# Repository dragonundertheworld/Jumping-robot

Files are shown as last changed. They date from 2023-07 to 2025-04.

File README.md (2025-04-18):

# Micro Small Intelligent Jumping Robot

Project details can be found in [notion link](https://cherry-room-163.notion.site/?pvs=4)

## Project Overview

This project, developed at the University of Electronic Science and Technology of China (UESTC), focuses on creating a micro-sized intelligent jumping robot. Unlike many biomimetic designs, this robot utilizes engineering principles and a carbon fiber structure to achieve significantly higher jump heights, potentially exceeding 5 meters. The goal is to develop a robot capable of navigating complex terrains with potential applications in reconnaissance and defense.

## Key Features & Components

*   **High-Performance Jumping:** Employs carbon fiber legs for efficient energy storage and release, enabling high jumps.
*   **Engineering-Based Design:** Focuses on mechanical principles rather than direct biological imitation for maximizing jump height.
*   **Motor-Driven Actuation:** Uses a [`GA12-N20`](assets/GA12-N20.SLDPRT) DC geared motor (6V, 50r/min, 298:1 ratio) to wind a rope, compressing the carbon fiber legs for energy storage.
*   **Mechanical Latch Release:** A custom [`latch`](assets/latch.SLDPRT) and release arm system ([`releasing arm2.SLDPRT`](assets/releasing arm2.SLDPRT), [`releasing arm3.SLDPRT`](assets/releasing arm3.SLDPRT)) triggered by a [`楔形.SLDPRT`](assets/楔形.SLDPRT) (wedge) on the rope provides a rapid release mechanism.
*   **Power Source:** Utilizes a compact 7.4V, 180mAh LiPo [`电池.SLDPRT`](assets/电池.SLDPRT) (battery).
*   **Lightweight Construction:** Incorporates carbon fiber and other lightweight materials. CAD models for components are available in the [`assets/`](assets/) directory, including the main [`组装体.SLDASM`](assets/组装体.SLDASM) (assembly).

## Jumping Mechanism

1.  The motor rotates, winding a rope attached to the carbon fiber legs via a [`拉绳板.SLDPRT`](assets/拉绳板.SLDPRT) (rope plate).
2.  The legs bend, storing elastic potential energy.
3.  A wedge fixed to the rope moves upwards as it's wound.
4.  The wedge contacts and pushes open the latch mechanism.
5.  The release arm, no longer supported by the latch, swings down due to rope tension.
6.  The rope rapidly unwinds from the motor shaft, releasing the tension on the legs.
7.  The carbon fiber legs snap back to their original shape, converting stored potential energy into kinetic energy, launching the robot upwards.
8.  Elastic bands reset the release arm for the next jump cycle.

## Current Status

*   A physical prototype has been constructed and tested.
*   Achieved an estimated jump height of approximately 5 meters.
*   The time interval between jumps is around 10 seconds.
*   Demonstrated partial capability for repetitive jumping.

## Future Work & Planned Improvements

*   Develop and implement control systems for jump direction and aerial attitude stabilization (potentially using IMU, GPS).
*   Enhance the reliability and reduce potential jamming of the release mechanism.
*   Address potential delamination issues with the carbon fiber legs after repeated stress cycles.
*   Integrate control components (microcontroller, sensors, wireless communication like Bluetooth).
*   Implement obstacle avoidance capabilities.
*   Refine the overall mechanical structure and component interactions.

## Team & Advisor

*   **Team Members:** Gou Xuning, Cao Zhihan, Cui Chenguang, Tan Peijie
*   **Advisor:** Wei Dunwen
*   **Institution:** University of Electronic Science and Technology of China (UESTC)

## Assets

The [`assets/`](assets/) directory contains SolidWorks CAD files (`.SLDPRT` for parts, `.SLDASM` for assembly) detailing the robot's mechanical design.

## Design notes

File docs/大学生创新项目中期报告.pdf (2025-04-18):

# 电子科技大学创新创业项目

# 中期报告

## 项目名称： 微小型智能跳跃机器人

## 组内成员：苟栩宁、曹知寒、崔晨光、谈培杰

指导教师： | 魏敦文

## 2023 年 4 月 23 日

I

摘要

本文主要研究一种基于工程原理的微小型智能跳跃机器人，其可在复杂环

境中实现跳跃，跳跃高度远超以往的仿生机器人，在国防军事领域存在极高的

应用前景。目前研究内容主要包括：设计了机器人基于碳纤维的跳跃组件，包

括碳纤维足、电机、锁存器、吊臂 、释放臂等部件，能够通过电机的旋转带动

实现机器人的准备及跳跃。同时初步探讨设计了机器人实现重复跳跃的组件，

为跳跃机器人的可持续性运行奠定了基础。

关键词：碳纤维足；跳跃机器人；重复跳跃

I

目录

摘要 | I

1.绪论

## 1.1 课题研究背景及意义

伴随着无人系统技术的发展，微小型仿生跳跃机器人通过模拟动物如蚂蚱

袋鼠关节运动机理实现高性能高能效的跳跃运动，跳跃运动借助关节高爆发

力，实现高速的离散运动步态，具有很好的越障性能，同时具有体积小、隐蔽

性好、重量轻、成本低等特点，非常适用于非结构环境下探测和侦察任务，在

国防领域和民用方面都有着广泛的应用前景。

随着研究的深入，发现制约其发展的最大因素就是跳跃机理不够清晰以及

设计什么样的储能爆发结构到仿生跳跃的效果还不明朗。所以项目的研究重点

在于仿蝗虫腿部结构、腿部柔性关节与超弹性的耦合以及控制等方面，从而提

升跳跃机器人的跳跃性能。在军事国防和民用方面都有着十分广阔的应用前

景。

## 1.2 研究现状

几个世纪以来，科学家们探索了生物跳跃高度的极限，几十年来，工程师

们设计的跳跃机器人经常模仿或从生物跳跃者中汲取灵感。国外机器人已有不

少成品，如月球弹簧高跷是模拟蚂蚱的弹跳；气动双足机器人模拟人类的跳

跃；四足机器人仿照青蛙的跳跃模式；为穿越崎岖路段分别结合了滚动和滑行

运动技术的机器人；水上跳跃机器人模拟水黾的动作等等。国内目前也有仿

猫、仿蚂蚱、仿水黾的跳跃机器人以及电磁驱动的小型跳跃机器人。

其中仿蝗虫机器人基于扭簧的弹性变形激励，采用微型马达对其先蓄能后

释放的方式完成跳跃运动。在转向问题上同样采用了支撑腿设计，该团队在该

机器人上的创新在于着重研究群机器人的路径规划问题，并考虑结合组网技术

将其应用在远程家庭环境监控领域。最新的小型跳跃机器人的设计重点在于分

析蝗虫的运动模式，实现了爬行和跳跃两类运动。

2016 年，李涛等人从微观上分析超疏水性材料的疏水作用机理，在此材料

研究基础上，结合水黾的生物特征和运动机理，将该材料作为机器人的足端设

计了一种仿生水黾机器人，并据此分析了仿生水黾机器人的运动特性，为该团

队后续对仿生水黾机器人的动力学研究打下了基础。在李涛等人的研究基础

上，该团队成员通过实验和仿真研究了所使用的弹簧刚度、起跳角度和脚掌面

积对于机器人起跳性能的影响。

但是相比之下，基于工程原理的机器人的跳跃高度可能要高得多，因为它

的棘轮或旋转电机可以在重复行程或旋转过程中使得做功倍增。由于能量产生

的差异，仿生跳跃机器人和工程跳跃机器人最大化跳跃高度的设计并不相同。

因此，我们计划创造一种可以跳跃更高的设备。据计算，这将远远高于以前的

仿生跳跃机器人，比最好的生物跳跃机器人高出一个数量级，而更高的跳跃高

度意味着能适应更复杂的地形并拥有更广泛的应用，因此无论是在军事上还是

工程上，这样的机器人都有极好的应用前景。

## 1.3 研究内容及文章结构安排

### 1.3.1 研究内容

本项目研究一种可以远程操控的小型智能跳跃机器人，具备实时图像传

输，记录并发送自己的当前位置、通过无线蓝牙模块与智能手机等通讯设备进

行通信、远程调整跳跃方向及高度以进行复杂地形空中侦察等功能。

本跳跃机器人由直流减速马达驱动机构、碳纤维弹片及橡皮筋储能机构、

自动释放装置、弹簧复位结构和智能控制系统组成。考虑机器人在空中的运动

特征，利用 IMU 传感器实时监测机器人的运动状态，根据传感器的数据通过运

动规划和闭环反馈控制调整机器人的跳跃方向，借助 GPS 实现定位。控制马达

不同的旋转时间改变弹簧蓄力，以控制不同的跳跃高度。机器人的自动释放装

置和弹簧复位结构由 solidworks 设计，然后由高精度 3D 打印机打印。跳跃机

器人系统由接收器和发射机实现远程控制，它向机器人体内的微型 arduino 计算

机发送信号以控制跳跃的方向和高度。为了让机器人能够执行侦查任务，我们

优化了机器人的结构，使它能够跳跃到足够的高度。并改进蓄能装置，使机器

人跳跃时间间隔大大缩短，以实现连续的工作。

为了实现上述功能，我们的设计方案主要如下：

该跳跃机器人包括轻型碳纤维跳跃结构、流线型破风机构、重心调整换向

结构、避障机构、支撑组件以及控制装置。

碳纤维跳跃结构包括: 跳跃用碳纤维片、十字形橡胶固定布、电机、弹簧

复位臂、闭锁以及多个钢质连接件。使用四个碳纤维作为跳跃主弓四个碳纤维

片在两端分别通过两个十字形橡胶固定布进行固定，下端与地面接触，上端通

过连接件与弹簧复位臂进行连接，弹簧复位臂上有一阻隔滑块，阻隔块连接在

绳上，绳随电机做往复运动，当阻隔滑块运动到与闭锁相接触时，滑块将闭锁

挤开，给予跳跃主弓巨大的瞬时力。从而通过电机的快速运动，实现跳跃主弓

的弯曲和复原，完成跳跃并落地，实现往复的运动过程。

流水线破风机构部分需要完成破风，使得跳跃式阻力更小，提高跳跃高

度。经过思考和实验，我们根据伯努利原理，设计了轻型材料制成的破风尖头

帽，该破风帽为流水线构型，能充分减少运动时的阻力。

重心调整换向机构包括舵机和质量块，控制元件接收到 app 传来的方向信

息或避障机构传来障碍物信息后，使舵机旋转一定的角度，从而使得质量块的

质量方向性发生改变，从而改变整体机构的重心，使机构的运动向目标方向转

换。

避障机构主要有使用深度相机和红外的双模控制，当相机和红外感受到前

方有障碍物时，会向控制芯片发送障碍物的位置信息，基于相机和红外的双模

工作，确保对障碍规避的稳定性。

控制装置具体包括：九轴传感器、电机通信模块、无线蓝牙通信模块、控

制芯片。以上传感器均安装在控制电路板上；控制电路板通过螺栓安装在与跳

跃机构的电机盒部分进行连接。值得注意的是，由于跳跃任务对轻型化的要

求，本次设计所使用的元器件均为低功率微型元件。

手机端 app，预期可以通过手机端向机构发送跳跃的方向、高度信息以及

实现跳跃机构的平稳停止，完成对机构的全方位控制。

### 1.3.2 文章结构安排

全文的章节安排如下：

第一章：首先简单介绍了微小型智能跳跃机器人课题的研究背景及意义；

然后介绍了目前相关仿生跳跃机器人的研究现状；最后描述了论文的研究内容

以及整体架构。

第二章：微小型智能跳跃机器人。介绍了目前本机器人的主要组成零件，

并对各零件的功能及参数进行了简要的介绍，也对跳跃机器人实现跳跃的整体

流程与原理进行了介绍。

第三章：项目研究结果。本项目建模并实现了一种微小型智能跳跃机器

人，基于碳纤维板的特性，突破了仿生机器人的生理极限，具有可观的跳跃高

度。同时指出了项目的部分创新点与后续的改进优化方向。

## 2.微小型智能跳跃机器人

在该项目中，机械部分的设计主要参考相关研究自主建模设计，采用质量

小、韧性强的碳纤维作为跳跃实现的主要部件，通过对电机的控制进而实现对

跳跃的控制，结构巧妙且具有极高的效率。

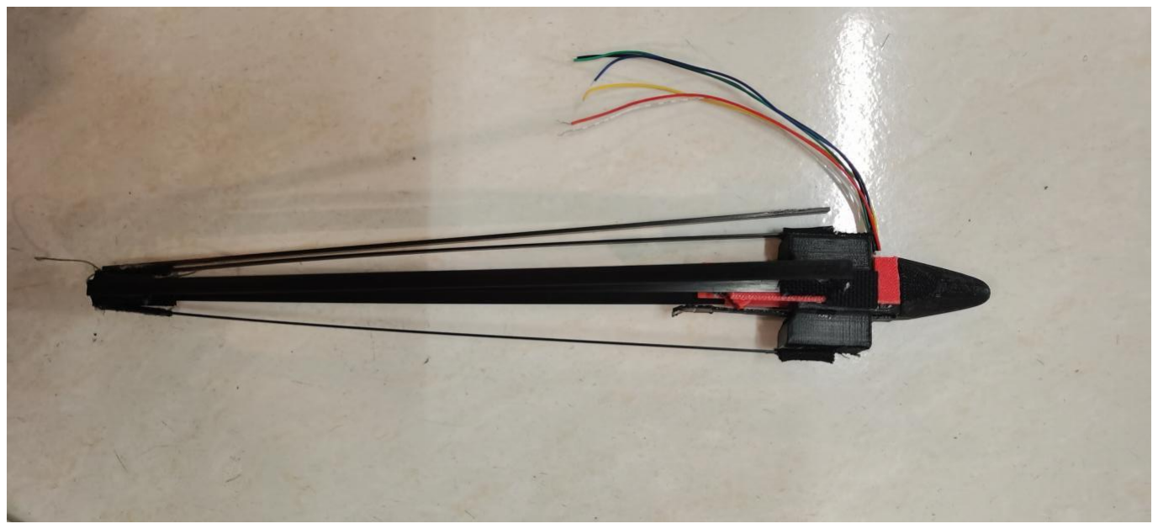
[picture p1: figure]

图 2 微小型智能跳跃机器人实物图

## 2.1 碳纤维跳跃组件

碳纤维跳跃结构包括: 跳跃用碳纤维片、十字形橡胶固定布、电源、电

机、弹簧复位臂、闭锁以及多个钢质连接件。使用四个碳纤维作为跳跃主弓四

个碳纤维片在两端分别通过两个十字形橡胶固定布进行固定，下端与地面接

触，上端通过连接件与弹簧复位臂进行连接，弹簧复位臂上有一楔形滑块，楔

形块连接在绳上，绳随电机做往复运动，当阻隔滑块运动到与闭锁相接触时，

滑块将闭锁挤开，跳跃主弓产生巨大的瞬时力实现跳跃。通过电机的快速运

动，实现跳跃主弓的弯曲和复原，完成跳跃并落地，实现往复的运动过程。

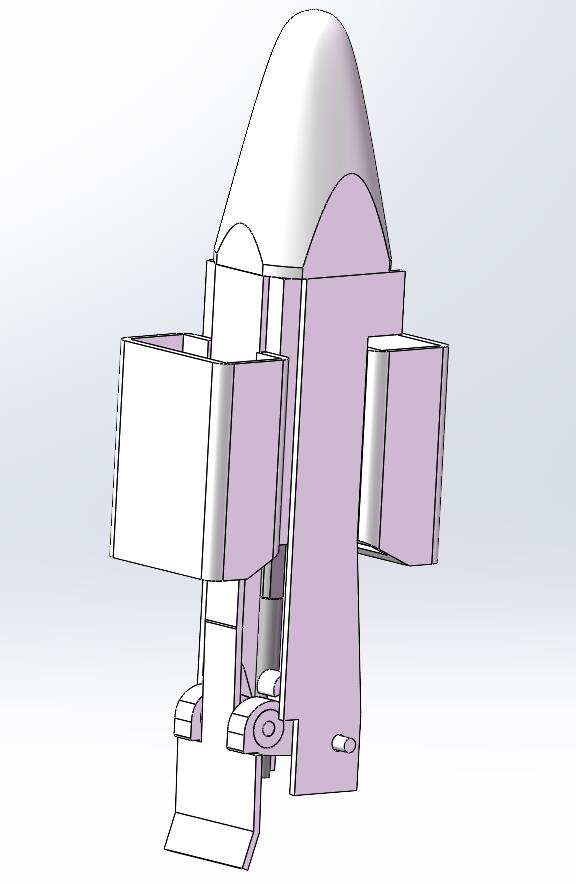
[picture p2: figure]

图 2.1 组合体三维图

以下是关于各主要部件部件的具体介绍：

### 2.1.1 碳纤维片

跳跃机器人主要依靠四个碳纤维片作为跳跃足，碳纤维片具有良好的韧

性，弹性好，能在发生较大形变后迅速恢复到初始状态，是作为跳跃机器人跳

跃足的绝佳选择。我们主要选取了四根长 260mm，宽 6mm，厚 1mm 的碳纤维

片作为跳跃足。除了作为跳跃足，因为其材料轻便，我们亦选取更小尺寸的碳

纤维片作为辅助足，用于将机器人支撑站立。

### 2.1.2 电机

由于碳纤维片的韧性极好，弹性系数较大，因此实验部件对电机扭矩的要

求较高，我们请教老师后，选取了参数为 6V，50r/min，减速比为 298 的

GA12-N20 微型直流减速马达，下面是电机的具体尺寸参数。

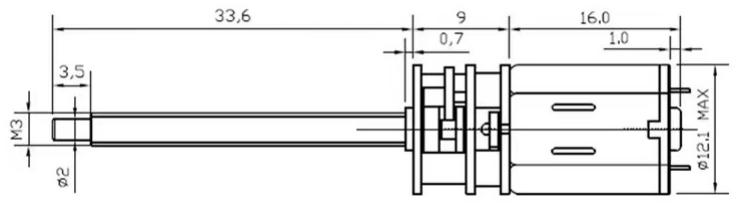
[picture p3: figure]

图 2.1.2 电机参数尺寸参数示意图

### 2.1.3 电源

基于电机参数与跳跃机器人的尺寸要求，我们选取了综合性能较好的中顺

芯 7.4V，180mAh 聚合物锂电池。电源的尺寸小巧，满足微型跳跃机器人的需

要，电源的更换也极为便利，能够满足微型机器人持续工作的需要。下面是电

源的详细参数。

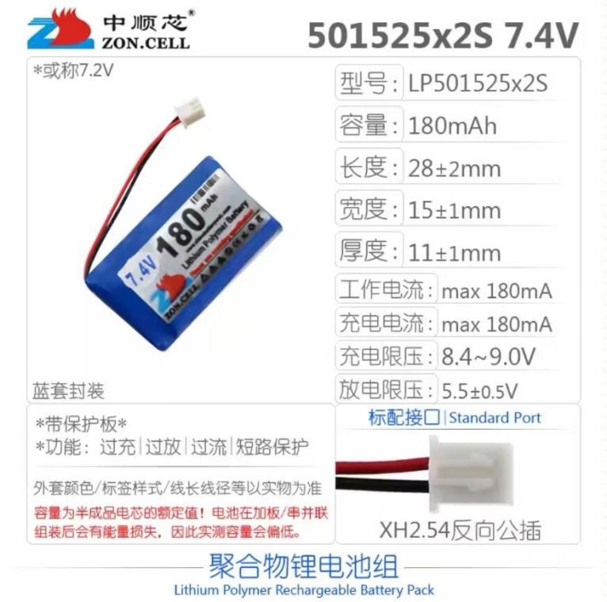
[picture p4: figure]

图 2.1.3 电源参数

### 2.1.4 锁存器

锁存器的主要功能是充当释放臂的支撑，当机器人在跳跃的准备阶段中，

释放臂搭在锁存器上，使电机在旋转的过程中能将绳子缠绕在轴上，进而实现

对跳跃的准备。当电机旋转到一定程度，固定在绳上的楔形会逐渐顶开锁存

器，实现对绳的释放，实现跳跃机器人的跳跃。

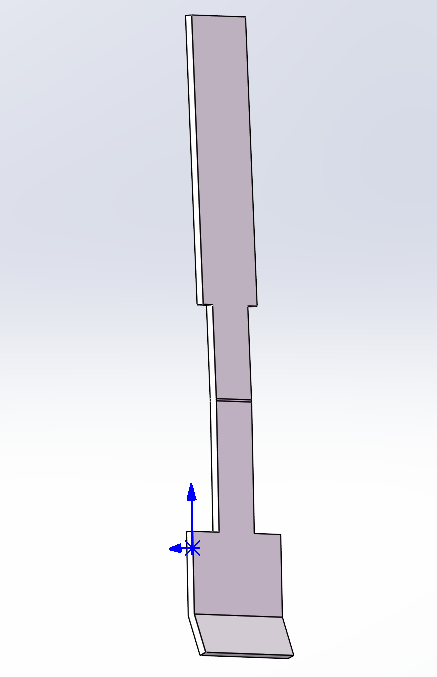
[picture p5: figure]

图 2.1.4 锁存器三维图

### 2.1.5 释放臂

释放臂的主要功能是释放在电机轴上缠绕的绳子，进而释放由碳纤维足储

存的弹性势能，完成跳跃。由于在未释放绳子时，释放臂搭在锁存器上,会承载

极大的压力，在释放后也会受到较大的冲击，因此我们选用不锈钢作为加工材

料。我们在其后端两侧加工了两凸出的柱体，用于与吊臂上加工的孔配合，实

现摆动轴线位置的确定。同时我们在前端两侧各开了一个直径 5mm 的通孔，在

其中配合直径 5mm 的轴承，轴承间穿插一小金属柱条，便于在收缩时减少绳与

其的摩擦。为了满足跳跃的可重复性，需要在其释放后仍能恢复到初始搭在锁

存器的状态，我们在其两侧设计了挂钩，通过橡皮筋与电机盒连接，实现位置

重置的需求。下面是其三维图展示。

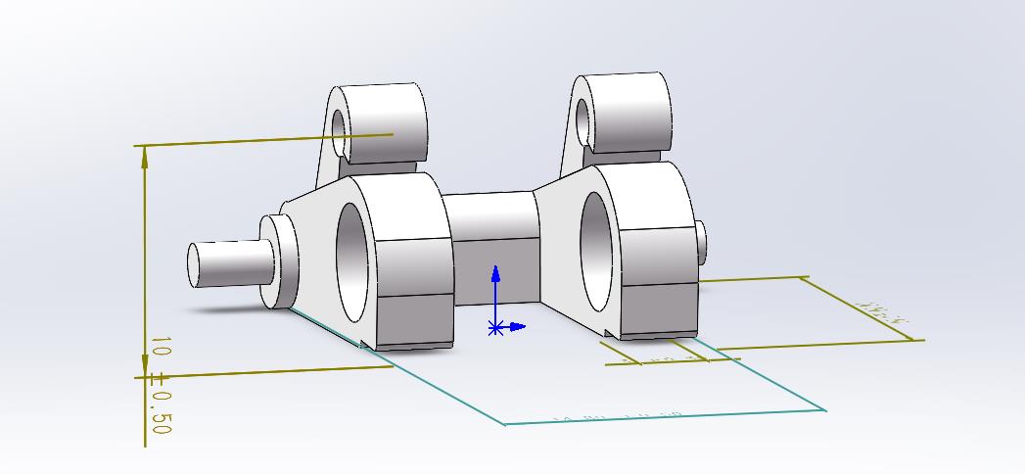
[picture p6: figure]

图 2.1.5 释放臂三维图

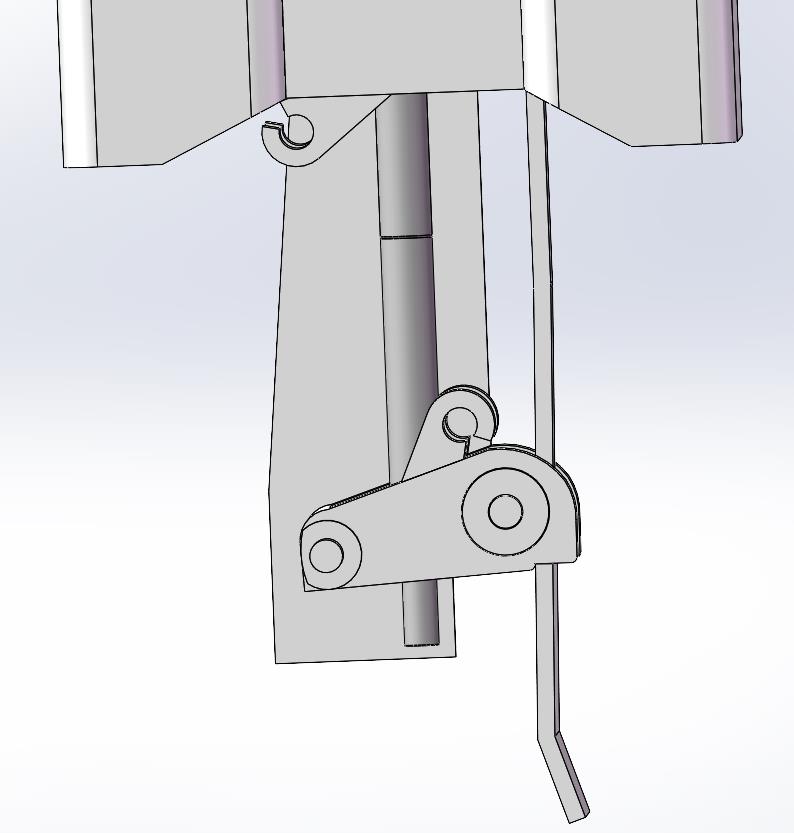
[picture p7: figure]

图 2.1.5 零件位置三维图

## 2.2 碳纤维跳跃组件跳跃原理

在跳跃初期，机器人整体横卧在地面，随着下达跳跃指令，机器人顶部的

电机即开始工作，带动绳缠绕在电机轴上，绳下端连接碳纤维足与十字形橡胶

固定布。随着绳子的不断缠绕，四个足会发生弯曲形变，逐渐鼓成“灯笼”状，

在辅助足的支撑下，逐渐站立起来。当绳子缠绕一定长度后，连接在绳上的楔

形块会上升到释放装置附近，随绳子缠绕其会顶到锁存器，搭在锁存器上的释

放臂 会随之失去支撑，在绷紧的绳子的压力下迅速下摆，电机轴上的绳子会失

去限位，对碳纤维足底部的拉力降为 0，碳纤维足迅速恢复原状，带动机器人

整体向上跳跃。

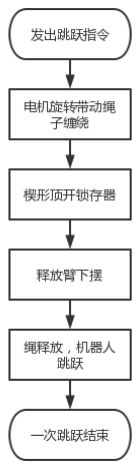
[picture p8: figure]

图 2.2 跳跃原理图

## 3.项目研究成果

## 3.1 研究成果

本项目的阶段性成果：我们参考论文，初步实现了微小型智能跳跃机器人

的模型建立与实现，其能够在电机不断的运转中，部分实现重复跳跃。

目前制造的模型跳跃的高度预估可达到 5m，跳跃的间隔时间为 10s，初步

实现了对预期跳跃高度的要求。

本项目的创新点包括如下几点：

1) 该项目采用碳纤维作为跳跃的主要实现材料，机器人整体的质量控制到

位，跳跃高度惊人。

2) 本项目采用的原理简明，机器人结构简单，在实际应用中稳定性较好，发

生失效的概率较低。

3) 本项目中采用电机绕绳压缩碳纤维片来实现跳跃的准备，对机器人跳跃的

控制仅需通过控制电机即可实现，大大降低了控制跳跃的难度。

4) 关于跳跃的可重复性，采用简单的橡皮筋便实现了位置重置，节约成本且

简单易行。

## 3.2 继续研究计划

1. 存在的问题：
1) 还没有实现机器人跳跃方向的控制和空中姿态的控制
2) 起跳时释放机构不能及时释放，偶见卡顿
3) 碳纤维板在多次收缩后容易出现剥落的现象
2. 拟解决的措施：
1) 改进机械结构
2) 开始控制部分的设计与调试
3) 改进零件相互配合的方式

致 谢

本论文是在魏敦文老师的悉心指导下完成的，我们要向魏敦文老师表达我

们最真挚的感谢。感谢您在智能跳跃机器人项目中给予我们的指导和支持。您

的专业知识和经验对我们的项目起到了至关重要的作用。您不仅仅是一位优秀

的老师，更是一位慷慨、耐心、负责任的导师。在您的帮助下，我们才能不断

顺利地推进这个项目，取得当下的成果。再次感谢您对我们的支持和鼓励，祝

愿您工作顺利，身体健康!

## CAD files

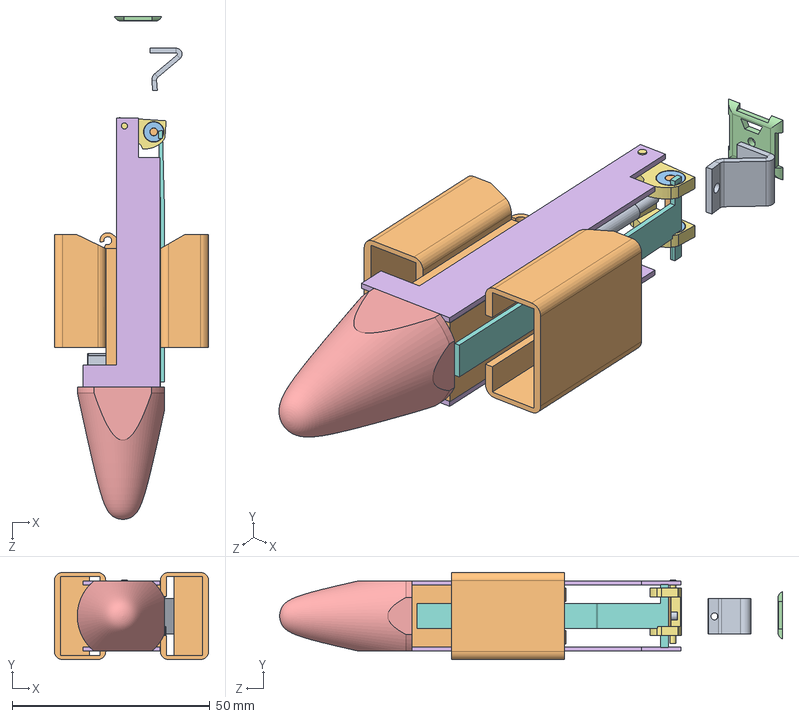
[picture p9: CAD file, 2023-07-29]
assets/组装体.SLDASM
39.0 x 22.0 x 127.2 mm
GA12-N20
马达盒
顶部
motor house1 x 2
releasing arm3
latch
楔形
中心棒
轴承 x 2
拉绳板

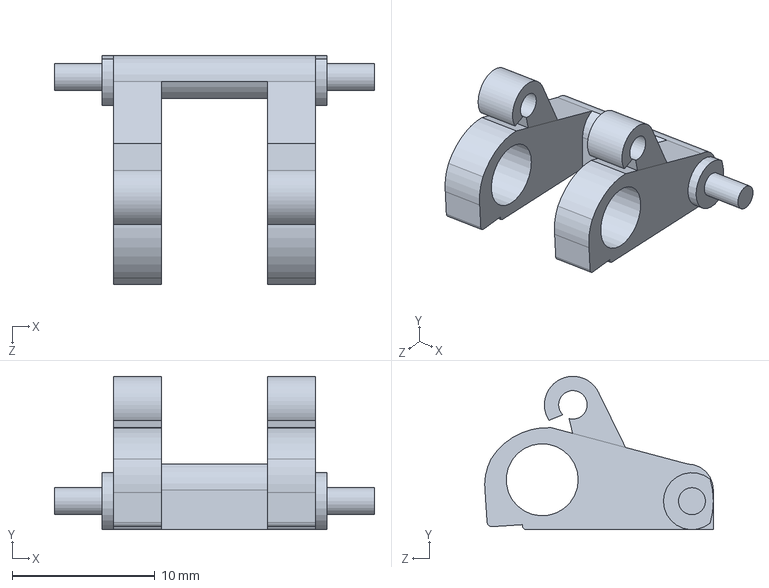
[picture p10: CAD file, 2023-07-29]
assets/releasing arm3.SLDPRT
22.4 x 10.8 x 16.0 mm

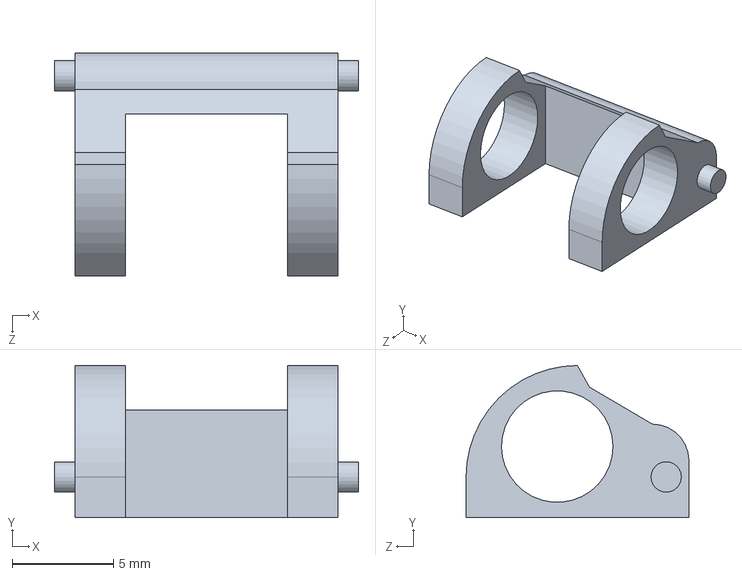
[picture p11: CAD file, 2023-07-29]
assets/releasing arm2.SLDPRT
15.0 x 7.50 x 11.0 mm

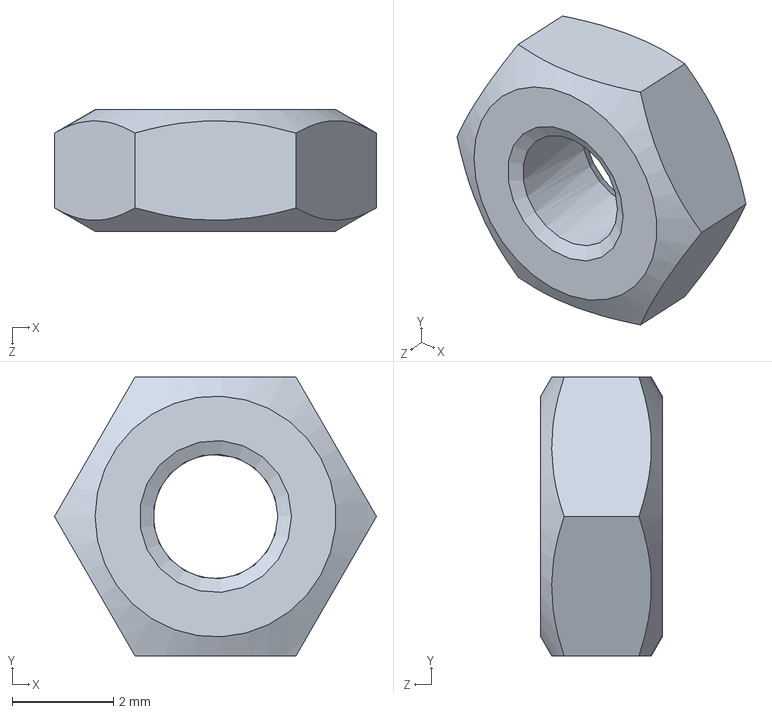
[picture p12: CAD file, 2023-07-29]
assets/固定螺母.SLDPRT
6.35 x 5.50 x 2.40 mm

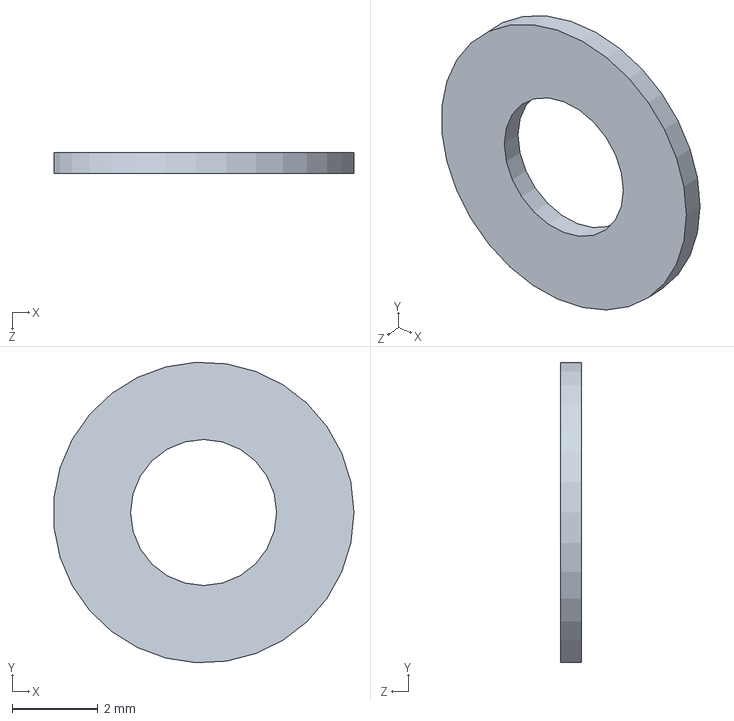
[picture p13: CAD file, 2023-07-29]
assets/垫圈.SLDPRT
6.98 x 6.99 x 0.5 mm

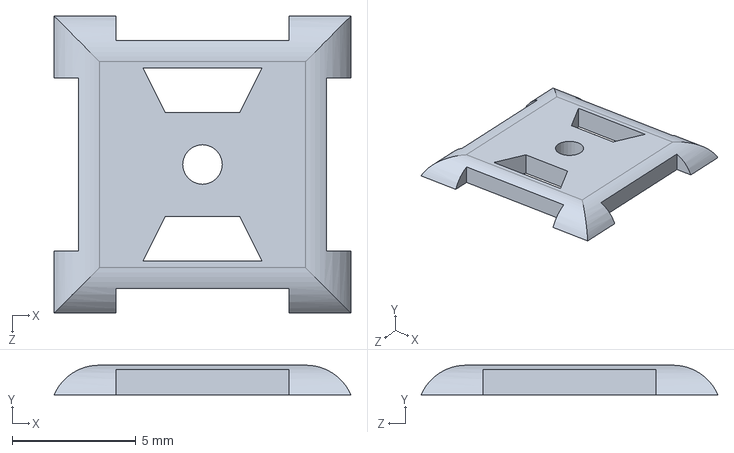
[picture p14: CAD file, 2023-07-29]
assets/拉绳板.SLDPRT
12.0 x 1.20 x 12.0 mm

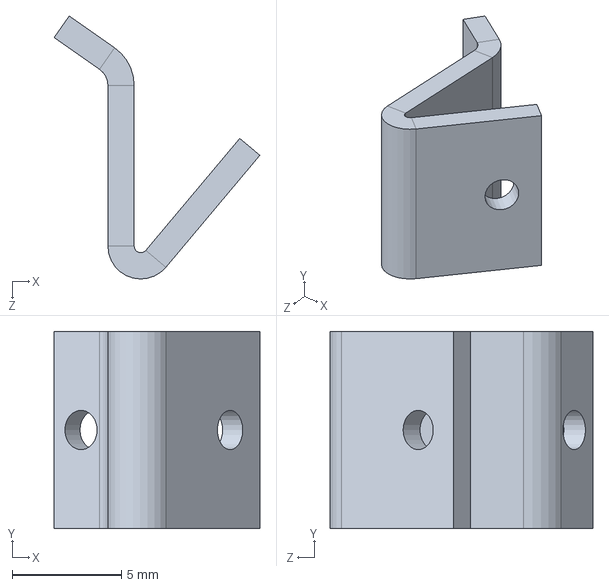
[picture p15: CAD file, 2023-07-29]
assets/楔形.SLDPRT
9.40 x 9.00 x 12.0 mm

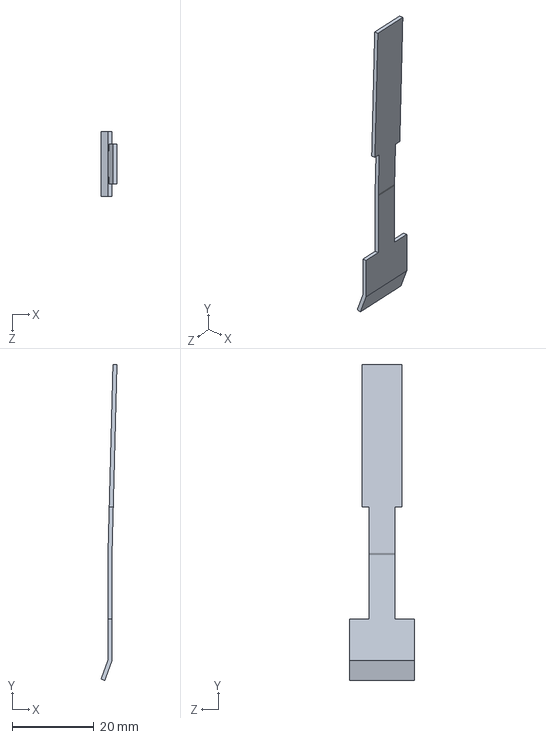
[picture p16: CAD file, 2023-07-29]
assets/latch.SLDPRT
3.93 x 77.5 x 16.0 mm

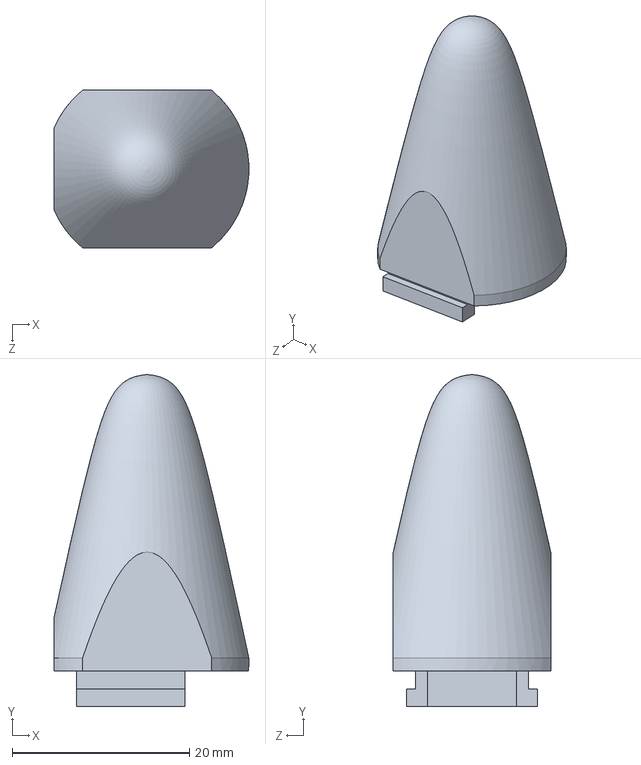
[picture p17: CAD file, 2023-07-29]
assets/顶部.SLDPRT
22.0 x 37.5 x 17.8 mm

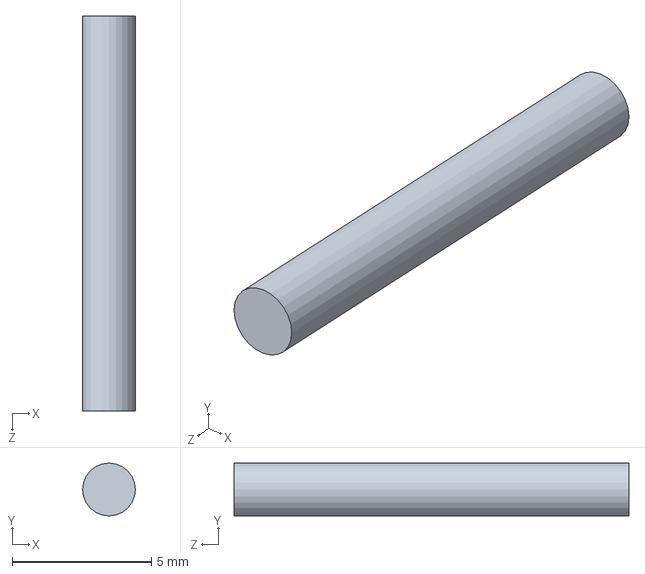
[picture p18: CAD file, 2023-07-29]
assets/中心棒.SLDPRT
1.90 x 1.90 x 14.2 mm

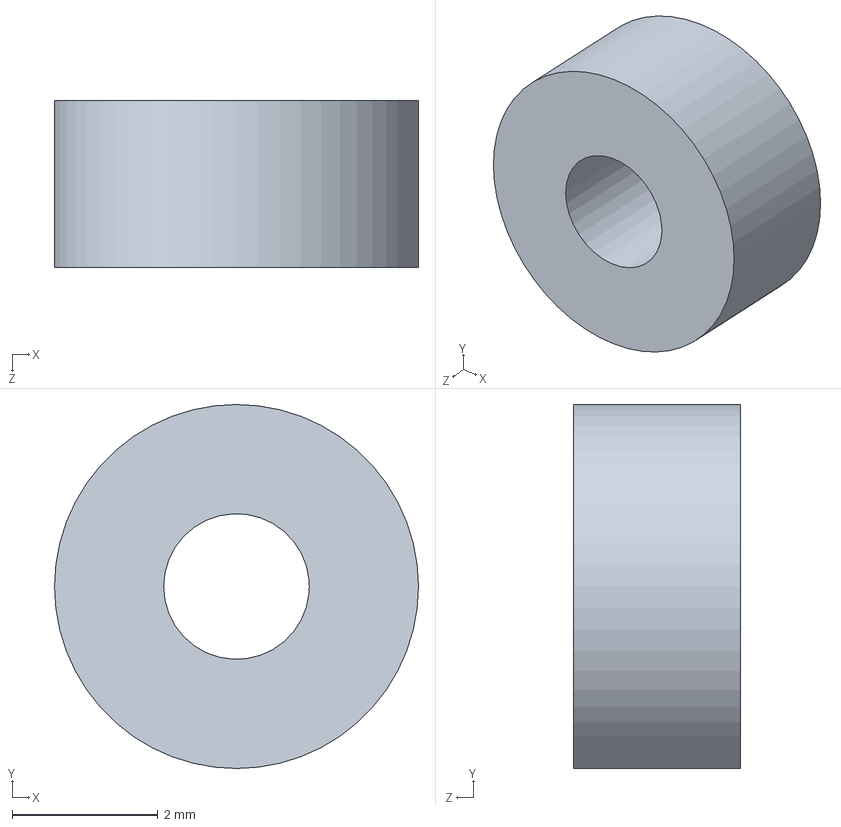
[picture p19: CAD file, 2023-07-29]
assets/轴承.SLDPRT
5.00 x 5.00 x 2.30 mm

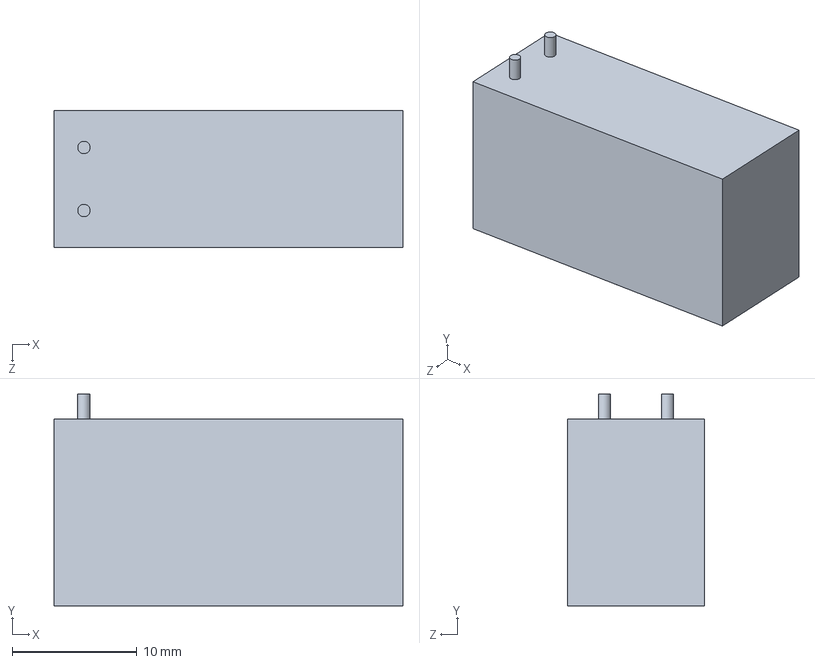
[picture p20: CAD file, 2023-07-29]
assets/电池.SLDPRT
28.0 x 17.0 x 11.0 mm

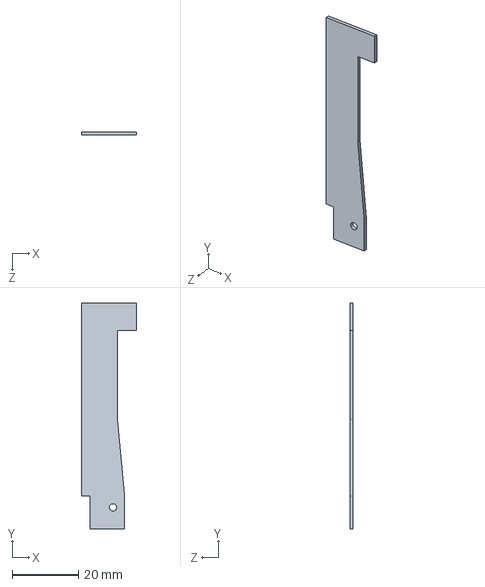
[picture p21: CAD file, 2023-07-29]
assets/motor house1.SLDPRT
16.5 x 68.0 x 1.00 mm

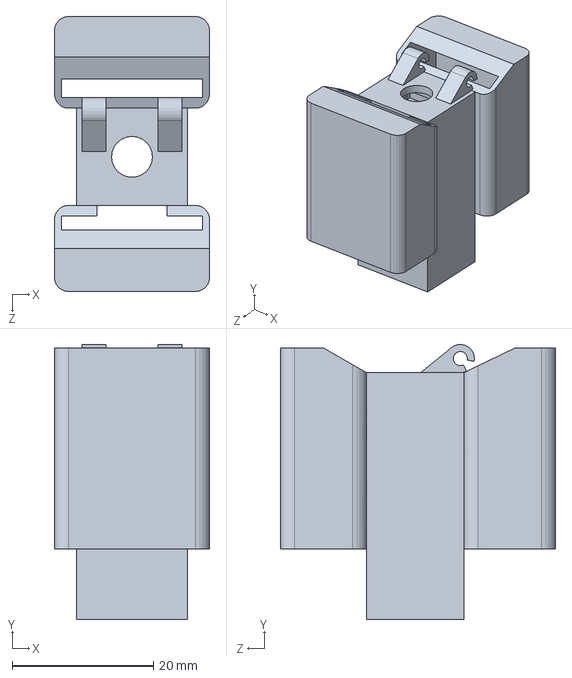
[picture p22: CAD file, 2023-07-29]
assets/马达盒.SLDPRT
22.0 x 39.0 x 39.0 mm
